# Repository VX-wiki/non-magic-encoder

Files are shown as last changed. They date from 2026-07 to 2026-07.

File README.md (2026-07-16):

# Non-Magic Encoder

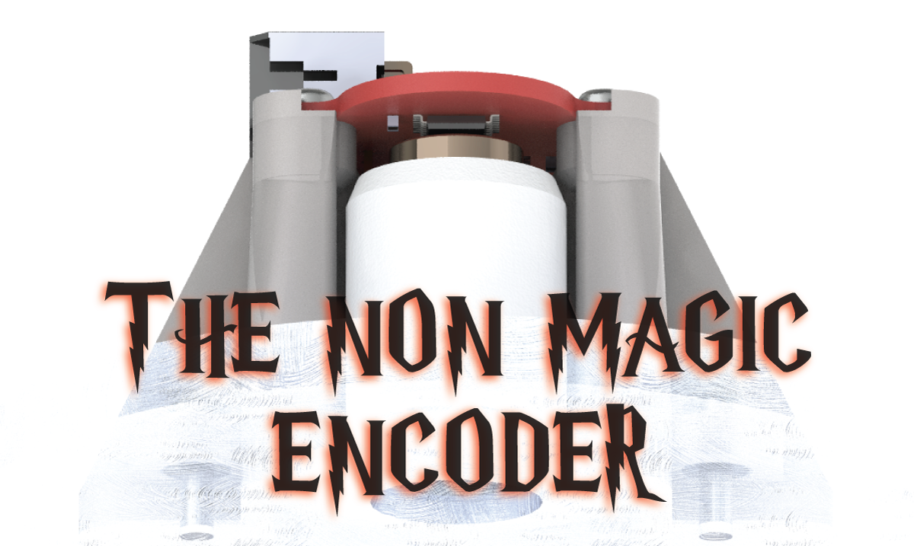
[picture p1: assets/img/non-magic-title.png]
Non-Magic encoder











> ### ⚠️ Read this first: do you actually need one?
>
> **The stock Broadcom optical encoder is magically good when it works.** It is accurate, clean, and there is genuinely nothing wrong with it. Its *only* real weakness is that it is **mechanically fragile**: a delicate optical disc, optics, and aging plastic living in a hot, vibrating drivetrain. If your optical encoder is healthy, **leave it alone**. Nothing here will beat it.
>
> **Non-Magic has no magical properties.** Per the comparison report it does an essentially **identical job**: same current per torque, same heat, same efficiency. It will **not** make your scooter faster, more efficient, or smoother. Treat any apparent "improvement" as noise until proven otherwise.
>
> **This is still hardware under active test.** Non-Magic R1 is community beta with limited hours on a single bike. A lot can still go wrong: installation, adhesives, alignment, calibration, and long-term durability are all unproven at scale. The *one* thing it is meant to bring, better mechanical robustness from having no fragile optical disc, is **plausible but unproven**, and only earns that title after years of real-world service. The only honest reason to fit one today is that your optical encoder has already failed, or you are deliberately experimenting and accept the risk.

<p align="center">
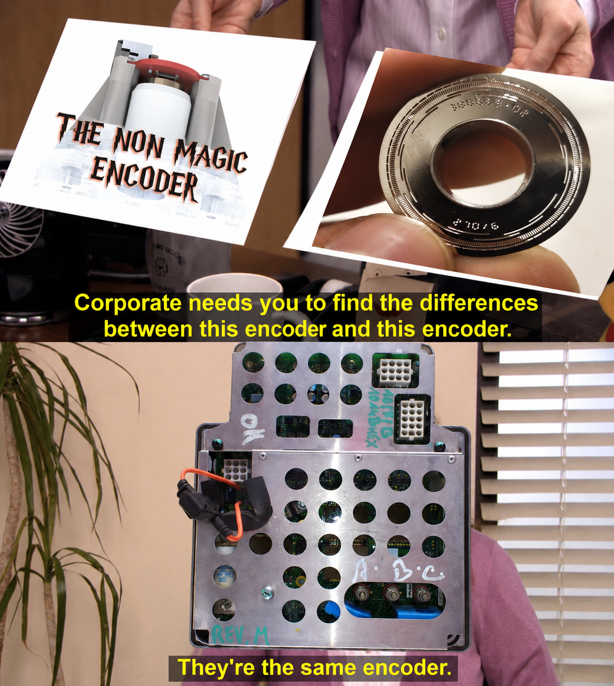
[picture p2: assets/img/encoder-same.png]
Corporate needs you to find the differences between this encoder and this encoder. They're the same encoder.
  
</p>

## Status and scope

Non-Magic R1 is **community-beta DIY hardware that is still actively under test.**

It has been bench-tested and road-tested on the author's single Vectrix VX-1 and, in those limited conditions, has shown no measurable power, efficiency, current, or heat penalty versus the OEM optical encoder. That is the *whole* of the evidence so far: one bike, a modest number of hours, one rider. It is a small-batch maker project, not a mass-produced, durability-qualified, or independently certified vehicle component.

**Expect problems.** Installation, calibration, adhesives, alignment, and long-term durability are all places where it can and may go wrong. The headline claim of better *mechanical robustness* over the optical encoder is plausible but **not yet proven**. It only earns that title after surviving years of heat, vibration, and moisture in service. Until then, assume Non-Magic is, at best, an *equal* to a working optical encoder, with robustness as an unproven bet.

Use it only if you understand the installation, calibration, and testing procedure, and only if you are comfortable being part of that test.

## What is this?

Non-Magic is a calibrated magnetic replacement encoder for the Vectrix VX-1 motor: a practical, mechanically robust drop-in for when the fragile stock optical encoder finally fails.

**Why "Non-Magic"?** There is a lot of magic out there: black-box encoders locked to one motor controller, with proprietary firmware you cannot read, repair, or replace. This is a *non-magical* encoder. It is open hardware you can modify, build, and experiment with as you please.

**Works with any stock motor controller firmware.** Non-Magic fully emulates the original optical encoder's parameters, with line-driver outputs matched to the original. There is nothing to reflash on the controller and no firmware lock-in. It drops in and behaves like the factory encoder. The goal is to **match** the optical encoder from a more mechanically robust platform, not to beat it.

A good encoder matters because the motor controller has to know rotor position before it can switch the windings cleanly. A weak or misaligned encoder can still make the wheel turn, but it can also add current ripple, heat, whine, rough commutation, lower efficiency, and extra stress on the inverter capacitors. The encoder is a small part, but it decides how cleanly the whole motor system works.

The comparison report now covers **two tests**, both against the factory optical encoder on the same stock controller firmware:

- **Bench (no-load).** On the stand, Non-Magic held its own on power and produced a slightly cleaner commutation signature through the main test band, with more sharply defined motor switching, run for run.
- **Road (loaded).** Ridden on public road under real load up to ~110 A, the two encoders were **indistinguishable**: same current for the same torque (within ~1%), the same heat in the inverter and DC-link capacitors, the same cruise/touring consumption (whole-ride energy 689 vs 690 Wh), and the same regen behaviour. The road test closes the bench's main open question: loaded efficiency and component heating.

The honest bottom line: across both tests the calibrated Non-Magic encoder performs **at least as well** as the OEM optical encoder, with no measurable power, efficiency, or heat penalty. "At least as well" is the ceiling of the claim, not a promise of better, and it still rests on a single bike over limited hours. Read the full comparison report here:

[Non-Magic encoder comparison report (rev2: bench + road)](assets/docs/Non-Magic-encoder-comparison-report-rev2-270626.pdf)

## Specifications

| | |
| --- | --- |
| Sensing IC | MT6835, 21-bit high-accuracy magnetic angle encoder |
| Core resolution | 21-bit |
| Accuracy | User auto-calibration with distortion compensation, target INL < ±0.07° |
| Max rotation speed | Up to 120,000 RPM |
| Operating temperature | −40 to +125 °C |
| Output drivers | AM26C31QDR automotive line drivers |
| Output interface | Connections match the original optical encoder |
| Controller firmware | Works with any stock motor controller firmware. Fully emulates the original encoder's parameters, no reflash, no lock-in |
| Mounting | Robust mechanical mount, designed for a hot, vibrating drivetrain |

## Buy DIY Kit

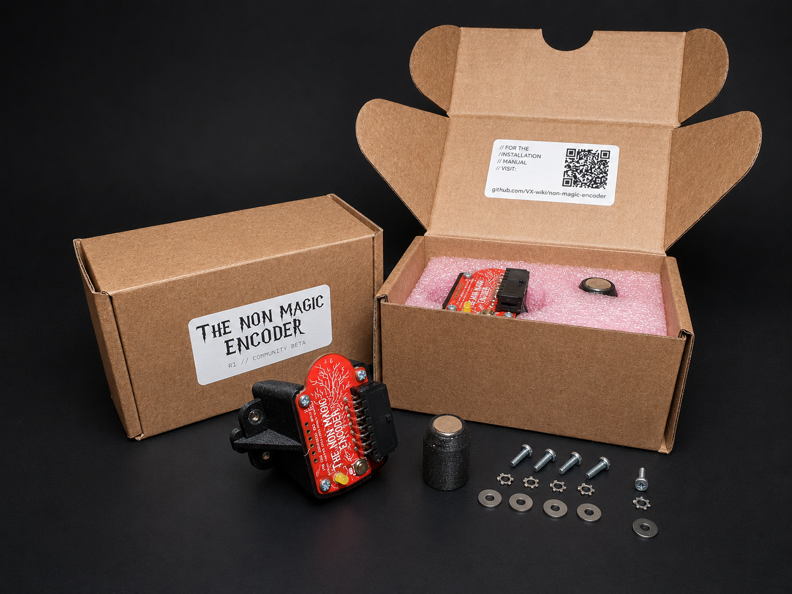
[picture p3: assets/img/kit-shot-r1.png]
Non-Magic encoder DIY kit


<p align="center">
  <a href="https://buy.stripe.com/eVq7sK1AGdGB0a8gIo7Re01">
    
  </a>
  <br>
  <sub>self installation required · community-beta, install at your own risk</sub>
</p>

<p align="center">
  <strong>Proceeds support a non-profit makerspace in Riga, Latvia.</strong><br>
  <sub>The first R1 batch is personally funded by the maintainer; Stripe proceeds after payment processing fees go to the makerspace.</sub>
</p>

> ⚠️ **DIY community-beta kit: read before buying or building.**
>
> This is a limited R1 DIY repair/experimenter kit for experienced Vectrix VX-1 owners. It is **not** a plug-and-play consumer accessory: not type-approved, not independently safety-certified, and not supplied as a certified road-use safety component.
>
> Installation requires correct mechanical fitment, magnet alignment, adhesive use, wiring, encoder self-calibration, and motor-controller offset calibration. Incorrect installation or calibration can cause rough commutation, loss of propulsion, overheating, motor or controller damage, or unsafe vehicle behaviour.
>
> Buy only if you can install, inspect, calibrate, and test it yourself. Start with the wheel lifted, test gently, and stop using it immediately if you hear abnormal noise, feel rough running, see faults, or notice unusual heat.
>
> Nothing here limits any mandatory rights or remedies that cannot legally be excluded.

Every board is **tested, programmed, and conformal coated** before it ships. The kit includes **all required parts except threadlocker and adhesive** (listed as consumables below).

## PCB

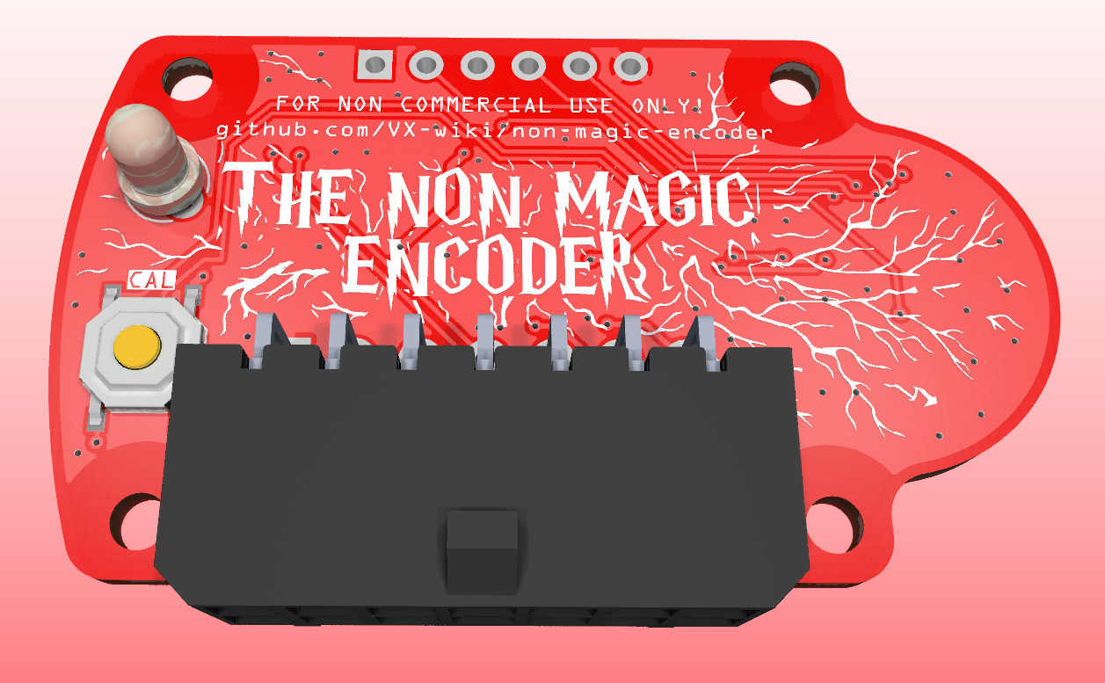
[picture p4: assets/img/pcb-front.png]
Non-Magic PCB front


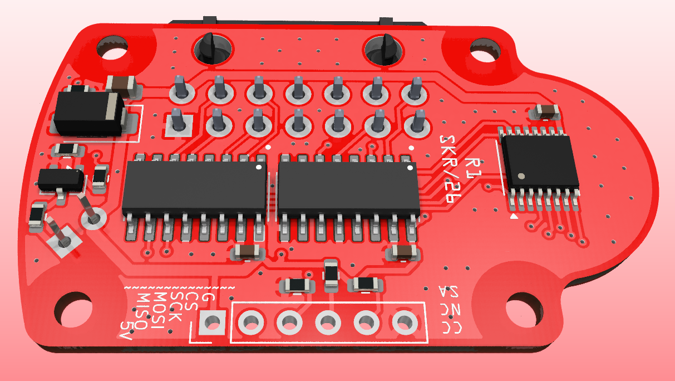
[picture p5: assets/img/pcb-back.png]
Non-Magic PCB back


## How to Install and Use

> ⚠️ **Safety first: read before you touch anything.**
>
> - **Always on the centre stand.** Every calibration and test step below is done with the bike on its centre stand and the **driven (rear) wheel off the ground and free to spin**. The motor can spin that wheel on its own during offset calibration, so never do this with the wheel able to drive the bike.
> - **High voltage.** The Vectrix runs on high-voltage traction electronics. Treat the battery, controller, and wiring as live and dangerous at all times, and take every sane high-voltage precaution whenever you work on the bike.

Installation walkthrough video:

https://github.com/user-attachments/assets/6c1a84cd-9490-44e6-9311-1ca9467ff3d4

A key advantage of Non-Magic is that it **self-calibrates once installed**. The on-board MT6835 builds its own angle-error correction map while the rotor turns slowly. You just spin the rear wheel at roughly 5 km/h with a hand drill pressed against the tyre and hold the calibration button. No special rig, no PC required for this step.

### 1. Mechanical installation

1. **Remove the original encoder assembly.**
2. **Clean the area thoroughly.** No dust, grease, oil, or other contaminants may remain in the motor encoder cavity. A clean, dry surface is critical for both the adhesive bond and the magnetic reading.
3. **Install the magnet holder.** Apply adhesive and push the magnet holder on until the motor shaft bottoms out inside it. Watch the slot in the shaft and the magnet holder; they must align cleanly. Allow the adhesive to set if possible.
4. **Attach the encoder assembly to the motor case.** Use threadlocker on the bolts. Fit each bolt with a wide washer and a serrated washer. **Do not overtighten.**
5. **Connect the encoder connector.**

There are **two separate calibrations**, and they must not be confused:

- **Encoder ASIC self-calibration** (Section 2) calibrates the **encoder**. It runs on the encoder's own MT6835 chip and corrects the magnetic sensor's per-revolution angle-error map, using the **encoder's calibration button and LED**.
- **Motor offset calibration** (Section 3) calibrates the **inverter**. It runs on the Vectrix motor controller, either in diagnostic software or via the throttle/brake/ignition "combo", and teaches the controller the fixed angle between encoder zero and the rotor's magnetic zero.

Do both, in this order. They are different procedures on different hardware; the encoder button does not trigger the controller offset cal, and the controller combo does not trigger the ASIC self-cal.

### 2. Encoder ASIC self-calibration (on the encoder)

1. **Power on the bike, but do not try to start it.**
2. **Turn the wheel by hand and watch the LED.** It should give **5 pulses per wheel revolution**. If it does, the magnet and alignment are good.
3. **Run the calibration spin.** Put the bike on the centre stand and spin the rear wheel with a hand drill pressed against the tyre, holding roughly **5 km/h** (read off the dash or scooter diagnostic software).
4. **Hold the calibration button.** Calibration needs **more than 64 rotations** to complete; expect to hold the button for under ~20 seconds. **THE SPEED TARGET IS APPROX 10-30-ish km/h, so no need to be very precise. If you are too slow or fast- it will just fail and let you know with the led** The LED shows progress:

   | LED state | Meaning |
   | --- | --- |
   | Half brightness | Calibration in progress |
   | Dim | Calibration failed |
   | Full on | Calibration succeeded |

5. **Turn the bike fully off** once calibration succeeds.

### 3. Motor offset calibration (on the inverter)

After the on-board self-cal, the motor controller still needs its own encoder-offset calibration.

**With the Vectrix diagnostics software:** turn the bike on and run the encoder calibration from the diagnostic application. Note this needs a **PeakCAN cable** to talk to the controller. If you don't have one, you can't use the software, so use the combo procedure below instead.

**Without software, the built-in combo procedure:** the controller has a hidden calibration mode you trigger straight from the bars, no cable or software required. (This is the same throttle/brake/ignition combo Vectrix documented for the original optical encoder; it works identically here.)

1. Put the bike on its **centre stand** and confirm the rear wheel is off the ground, free to spin, and the bike is stable.
2. Fold up the side-stand / kickstand.
3. Make sure the ignition key is in the **OFF** position.
4. Press the kill switch to the **RUN** position.
5. Turn the throttle **fully open** and squeeze the **left brake** lever, and hold both.
6. While still holding throttle and brake, turn the ignition **ON**.
7. Keep holding until the dashboard activates and the **WRENCH** icon / tell-tale light stays on, then release the throttle and brake.
8. Calibration starts automatically: the wheel begins to rotate and the speedometer needle sweeps from 0 km/h up to 120 km/h and back to zero.
9. After a few seconds the **WRENCH** icon disappears. Calibration is done.
10. If the process repeats itself over and over, the encoder cannot find a valid calibration; it requires inspection, cleaning, or replacement.

> **Caution:** the bike is still in GO mode during and after this procedure. Turning the throttle will activate the motor.

Then test gently first, listening for rough commutation or abnormal motor/controller heat.

> **Note: check your phase wiring.** The author's bike came equipped with a "magic" commercial magnetic encoder as purchased, and its motor phase wires were connected A-B, B-C, C-A. Neither the optical nor the magnetic encoder would work until the phases were swapped back to their respective factory positions: A-A, B-B, C-C. If the motor refuses to run or commutates badly regardless of encoder calibration, verify the phase wiring is in its correct factory order before troubleshooting the encoder further.

Installation consumables:

| No | Name | Qty | Notes | Link |
| ---: | --- | ---: | --- | --- |
| 1 | Threadlocker, blue or red | as needed | For encoder holder to motor case | commodity |
| 2 | Magnet holder to motor adhesive | as needed | Preferred order: automotive gasket maker, toughened cyanoacrylate, two-part epoxy, threadlocker | commodity |

## Make Your Own

Or make your own. The full design sources are below.

> ⚠️ **License first.** These files are released under **CC BY-NC-SA 4.0**. You may build, modify, and share them, but you may **not sell them or profit in any way**, and any derivative must stay under the same license. See [License](#license). No magic, no freeloading.

**Total cost is roughly €25–60 per unit**, depending on how you scale and source the parts and what tools and materials you already have on hand.

The DIN fasteners are standard commodity parts; source them from any supplier by their DIN number.

| No | Name | Image | Qty | Notes | Link |
| ---: | --- | :---: | ---: | --- | --- |
| 1 | Main PCB | Main PCB front | 1 | Gerbers + assembly files | [production archive](hardware/kicad/production/non-magic-encoder-r1.zip) |
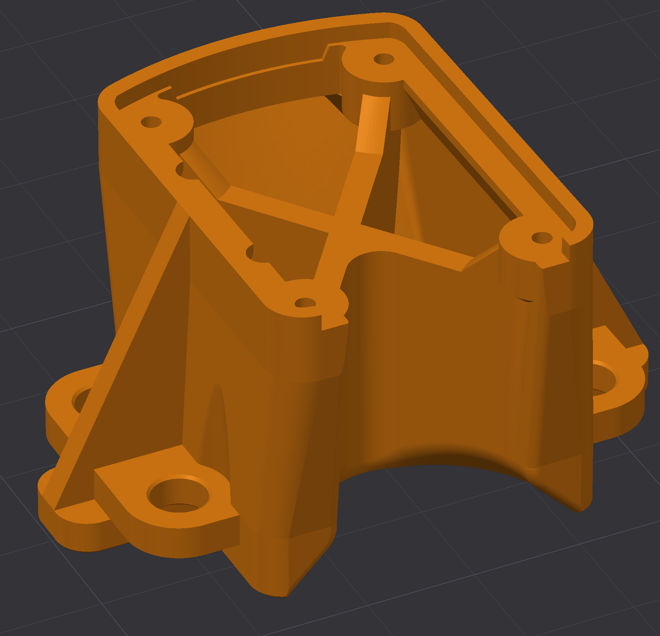
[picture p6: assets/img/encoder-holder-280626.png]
Printed PCB holder
| 2 | Printed PCB holder* |  | 1 | FDM PA6-GF, PA6-CF, PPS-CF, or MFJ PA12-GB. IMPORTANT! | [STL](hardware/printed-parts/encoder-printed-holder-r1.STL) |
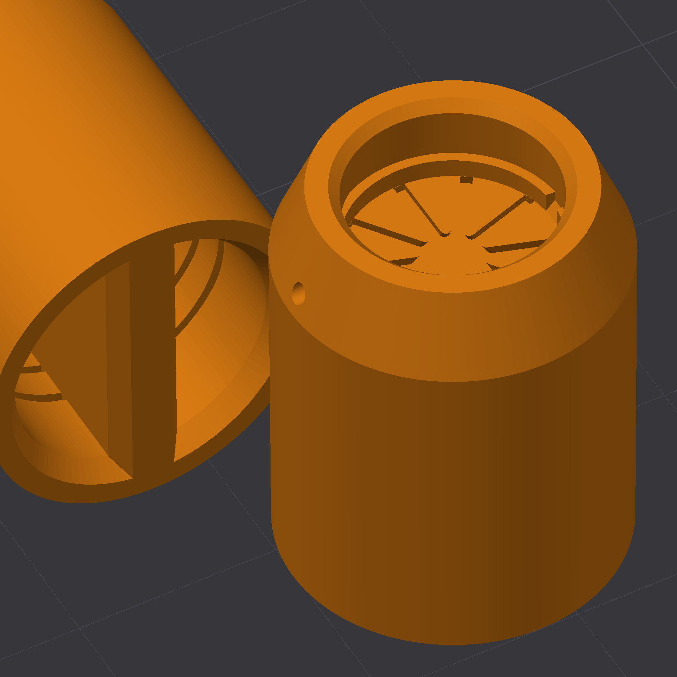
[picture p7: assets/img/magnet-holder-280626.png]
Printed magnet holder
| 3 | Printed magnet holder* |  | 1 | FDM PA6-GF, PA6-CF, PPS-CF, or MFJ PA12-GB. IMPORTANT! | [STL](hardware/printed-parts/magnet-holder-r1.STL) |
| 4 | 3M DP8910NS adhesive | | 0.1 g | Bonds the magnet to the printed nylon holder. Alternate adhesive can be used, but it is risky; see note below | [3M](https://www.3m.com/) |
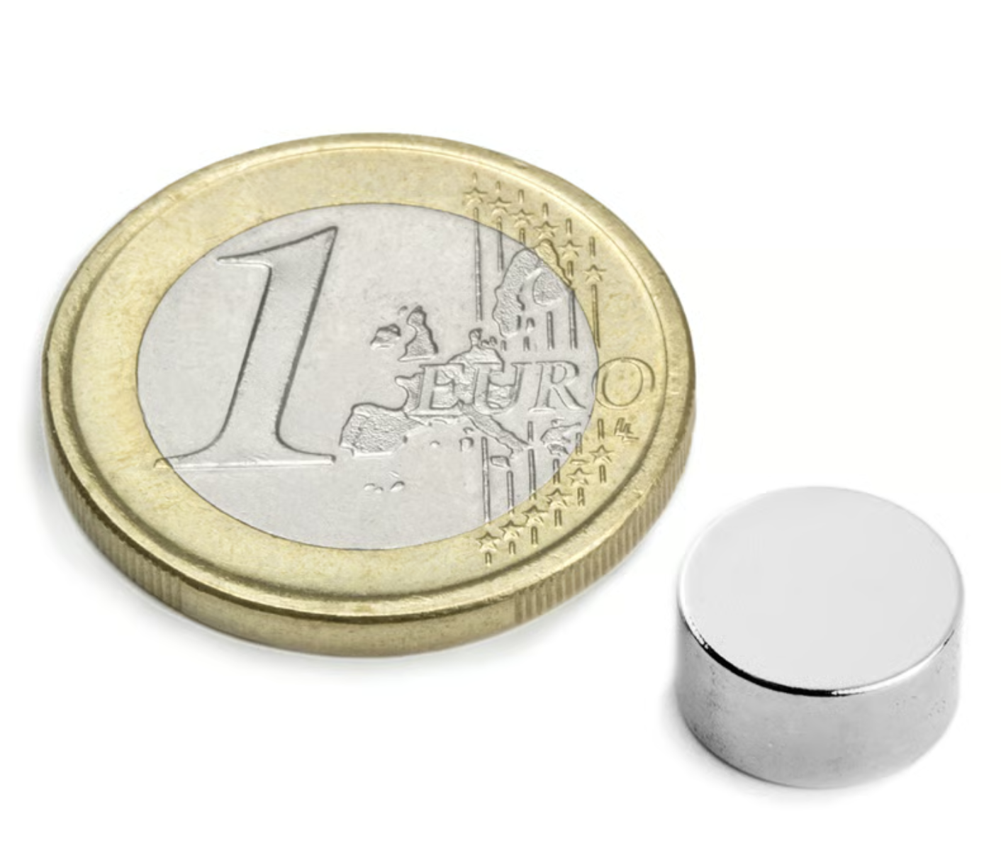
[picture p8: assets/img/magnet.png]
10x5 neodymium magnet
| 5 | 10x5 neodymium magnet |  | 1 | N45 or better, diametrically magnetized | commodity |
| 6 | Sleeve DIN 7340 | | 4 | Cu, 2.6 x 5 x 3 | commodity |
| 7 | Washer DIN 9021 | | 4 | M2.5, OD8 | commodity |
| 8 | Washer DIN 6798 Type A | | 4 | M2.5 | commodity |
| 9 | Bolt DIN 7985 | | 4 | M2.5, length to suit installation | commodity |
| 10 | Screw DIN 7981 ST 2.0 x 6 | | 4 | EJOT PT is better | commodity |
| 11 | Conformal coating | | as needed | Weatherproof the populated PCB; see note below | commodity |

*The encoder lives in a harsh environment. You must use glass-filled high-performance material for the encoder support. PA6-GF is used in the current units. Standard SLS PA12 or PA11 may not be up to the task.

**Why the 3M DP8910NS adhesive matters:** nylon (PA6 through PA12) is a *low surface energy* plastic, so most common adhesives will not key into it and the bond fails. DP8910NS is formulated specifically for low-energy substrates like nylon and polypropylene, which is why it is the recommended choice for bonding the magnet to the printed holder. Substituting a general-purpose adhesive is the most likely way to end up with magnet delamination.

**Conformal coating is important.** The encoder lives in a harsh place: heat, vibration, moisture, and contamination. Conformal coating the populated PCB is essential weatherproofing that protects against corrosion and conductive dirt. Factory-built kits ship already coated; if you build your own, do not skip this step.

### Design files

Everything needed to fabricate, assemble, or modify the board:

| File | Description |
| --- | --- |
| [Schematic (PDF)](hardware/non-magic-encoder-r1-schematic.pdf) | R1 schematic |
| [Production archive (ZIP)](hardware/kicad/production/non-magic-encoder-r1.zip) | Gerbers, BOM, and pick-and-place for fabrication |
| [KiCad project](hardware/kicad/) | Editable sources (`.kicad_pro`, `.kicad_sch`, `.kicad_pcb`), libraries, and footprints |
| [Board STEP model](hardware/encoder-pcb-r1.step) | 3D model of the assembled PCB |
| [PCB holder STL](hardware/printed-parts/encoder-printed-holder-r1.STL) | Printed encoder support (glass-filled material, see note above) |
| [Magnet holder STL](hardware/printed-parts/magnet-holder-r1.STL) | Printed magnet carrier (glass-filled material, see note above) |
| [MT6835 datasheet](hardware/kicad/docs/MT6835_Rev.1.3.pdf) | Sensing IC reference |

## Informal Risk Assessment

A short FMEA-style note on the failure modes that actually matter on this hardware. This is not an ISO 26262 compliance claim, safety case, or certification. Severity, likelihood, and controllability are qualitative.

| Failure mode | Cause | Effect | Severity | Risk reduction |
| --- | --- | --- | --- | --- |
| Bad commutation | Magnet misalignment or skipped auto-calibration | Motor switches at the wrong angle, drawing excess current and overheating the motor and controller | Medium-High | Verify magnet centering and air gap, run the auto-calibration before riding, test first with the wheel lifted and watch for abnormal heat |
| Loss of board power | Cracked or shorted MLCC on the PCB shorts the supply and trips the upstream resettable fuse | Encoder goes dead, controller loses position, **motor coasts to a halt** (no torque, not a runaway) | Medium | Use quality MLCCs, avoid board flex during assembly and mounting, handle the populated PCB carefully |
| Mechanical failure | Magnet delamination: the magnet's adhesive bond to its holder lets go | Position signal is lost or wrong, propulsion drops out | Medium | Use the ranked adhesives with proper surface prep, use only glass-filled holder material, inspect after the first heat cycles |

Before riding: confirm the magnet is centred, run auto-calibration, and do the first run with the driven wheel lifted and a safe way to cut power. Treat any suspected encoder fault as stop-use until inspected. Road or public-use suitability is outside the scope of this project.

## Getting help

Two ways to get help or report a problem:

- **Open an issue.** [Create an issue in this repo](../../issues/new) for bugs, broken links, install trouble, or questions. This is the best place for anything others might hit too.
- **Chat with the community.** Reach out on WhatsApp in the **Open Source Magic Encoder** group, part of the wider **Vectrix Worldwide** community. It's the fastest way to get hands-on install and calibration help from other owners.

## Contributing

Contributions are welcome. Fork the repo, make your changes, and open an issue or pull request:

- **Found a bug or have an idea?** Open an issue first so it can be discussed.
- **Improved the hardware, holders, or docs?** Fork it, commit your changes, and open a pull request from your fork.

Anything you contribute is released under the same **CC BY-NC-SA 4.0** license as the rest of the project (see below), so improvements stay open for everyone.

## License

This project is licensed under the Creative Commons Attribution-NonCommercial-ShareAlike 4.0 International license (CC BY-NC-SA 4.0). See [LICENSE](LICENSE).

In plain terms:

- **Attribution.** You may use, build, and adapt this design, as long as you credit the project.
- **NonCommercial.** You may **not** sell these encoders or profit from them in any way. This is deliberate: the kits exist to fund a non-profit makerspace, not to seed a competing product.
- **ShareAlike.** If you modify and share the design, you must release your version under the same license, so improvements stay open for everyone.

**A simple test for what's allowed:** if you can order, say, 5–10 units from China and give them away to friends or others *at cost*, making no profit, taking no salary, charging nothing beyond what the parts and fabrication actually cost you, then the answer is **yes, that's fine**. The moment you mark them up, pay yourself, or otherwise come out ahead, it stops being NonCommercial and is no longer permitted.

This keeps the encoder in the spirit of the name: open to modify, build, and experiment with, but never to lock up or sell.

## Disclaimer

No warranties are provided. This is experimental hardware intended for off-road, testing, research, and maker use only. It is not certified as a road-use safety component.

Build, install, calibrate, and use it entirely at your own risk. You are responsible for checking fitment, alignment, wiring, calibration, local legality, and safe operation. The authors and contributors are not responsible for damage, injury, loss, or any other consequences from making, installing, modifying, or using this encoder.

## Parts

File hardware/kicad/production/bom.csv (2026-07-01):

Designator | Footprint | Quantity | Value | LCSC Part #
C2 | 0805 | 1 | 10u | C15850
C6, C7, C8 | 0603 | 3 | 100n | C14663
D1 | D_SMA | 1 | SMAJ5.0A | C5189780
D4 | LED_D3.0mm_Clear | 1 | LED
J1 | CONN-TH_14P-P3.00_HC-MX3.0-2X7AW | 1 | Conn_02x07_Odd_Even | C3294388
Q1 | SOT-23 | 1 | 2N7002 | C8545
R10 | 0603 | 1 | 100R | C4177
R11 | 0603 | 1 | 1k 0603 | C21190
R12, R6, R7, R8, R9 | 0603 | 5 | 100k | C25803
SW1 | SW-SMD_4P-L5.1-W5.1-P3.70-LS6.5-TL_H1.5 | 1 | CAL | C318884
U1 | TSSOP-16_4.4x5mm_P0.65mm | 1 | MT6835 | C2932578
U7, U8 | SOIC127P600X175-16N | 2 | AM26C31QDR | C337769

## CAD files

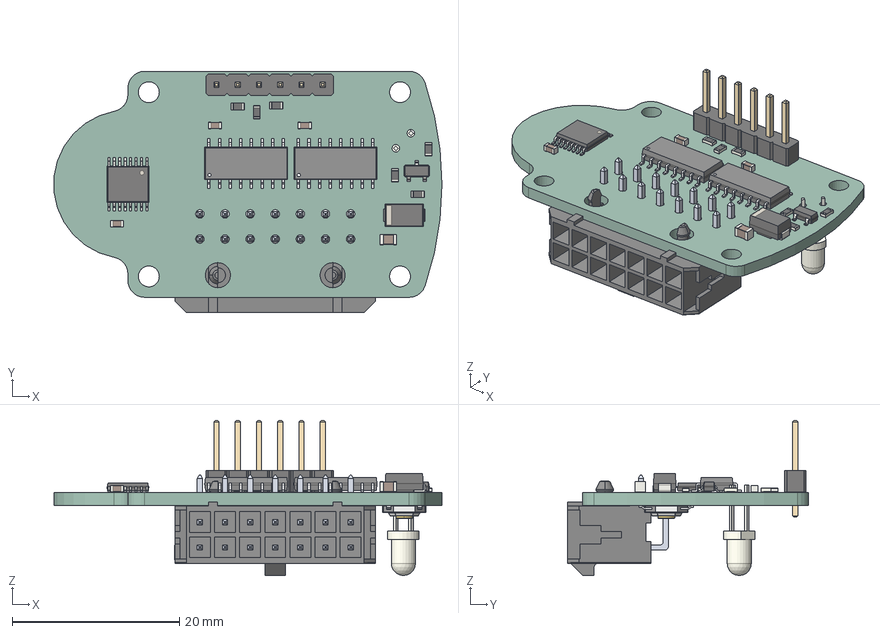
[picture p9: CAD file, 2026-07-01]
hardware/encoder-pcb-r1.step
46.3 x 28.8 x 18.5 mm
R_0603_1608Metric x 6
Body001 (Mirror #1) x 16
XY-plane x 24
X-axis x 24
PinHeader_1x06_P254mm_Vertical
C_0603_1608Metric x 3
SOT-23
D_SMA
C_0805_2012Metric
TSSOP-16_4.4x5mm_P0.65mm
SW-SMD_4P-L5.1-W5.1-P3.70-LS6.5-TL_H1.5
LED_D3.0mm_Clear
CONN-TH_14P-P3.00_HC-MX3.0-2X7AW
non-magic-encoder-r1_PCB

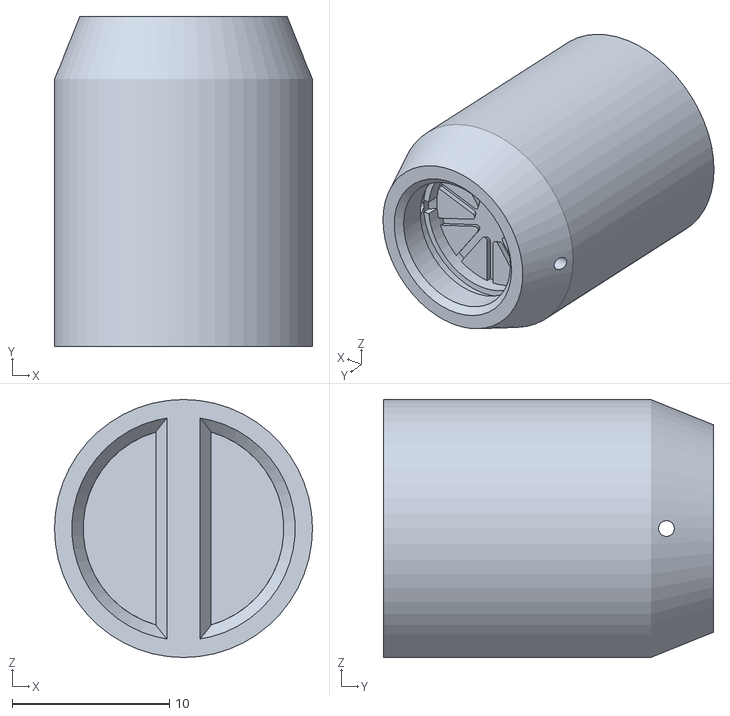
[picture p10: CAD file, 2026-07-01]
hardware/printed-parts/magnet-holder-r1.STL
16.4 x 21.0 x 16.4

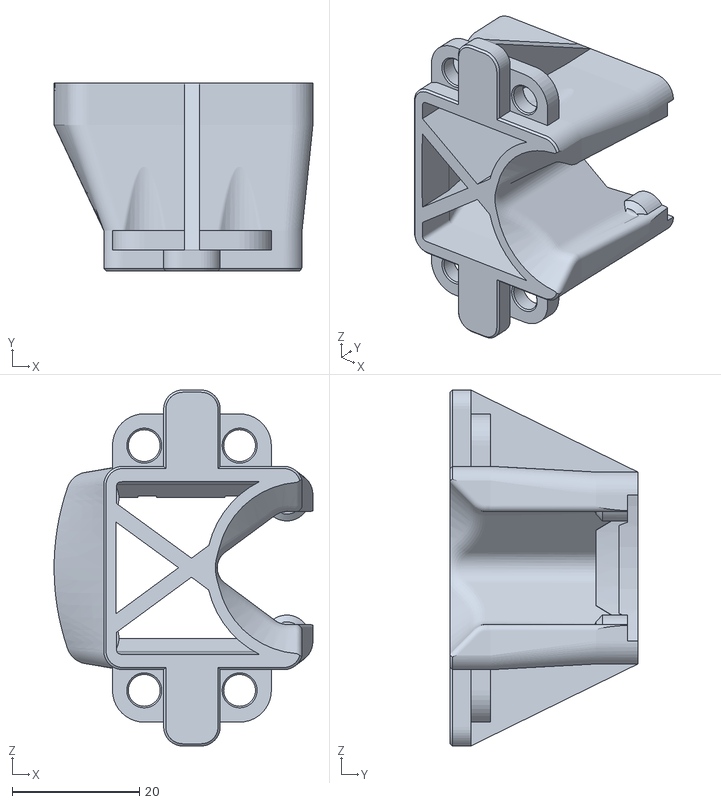
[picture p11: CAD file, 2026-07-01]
hardware/printed-parts/encoder-printed-holder-r1.STL
40.7 x 29.5 x 56.0

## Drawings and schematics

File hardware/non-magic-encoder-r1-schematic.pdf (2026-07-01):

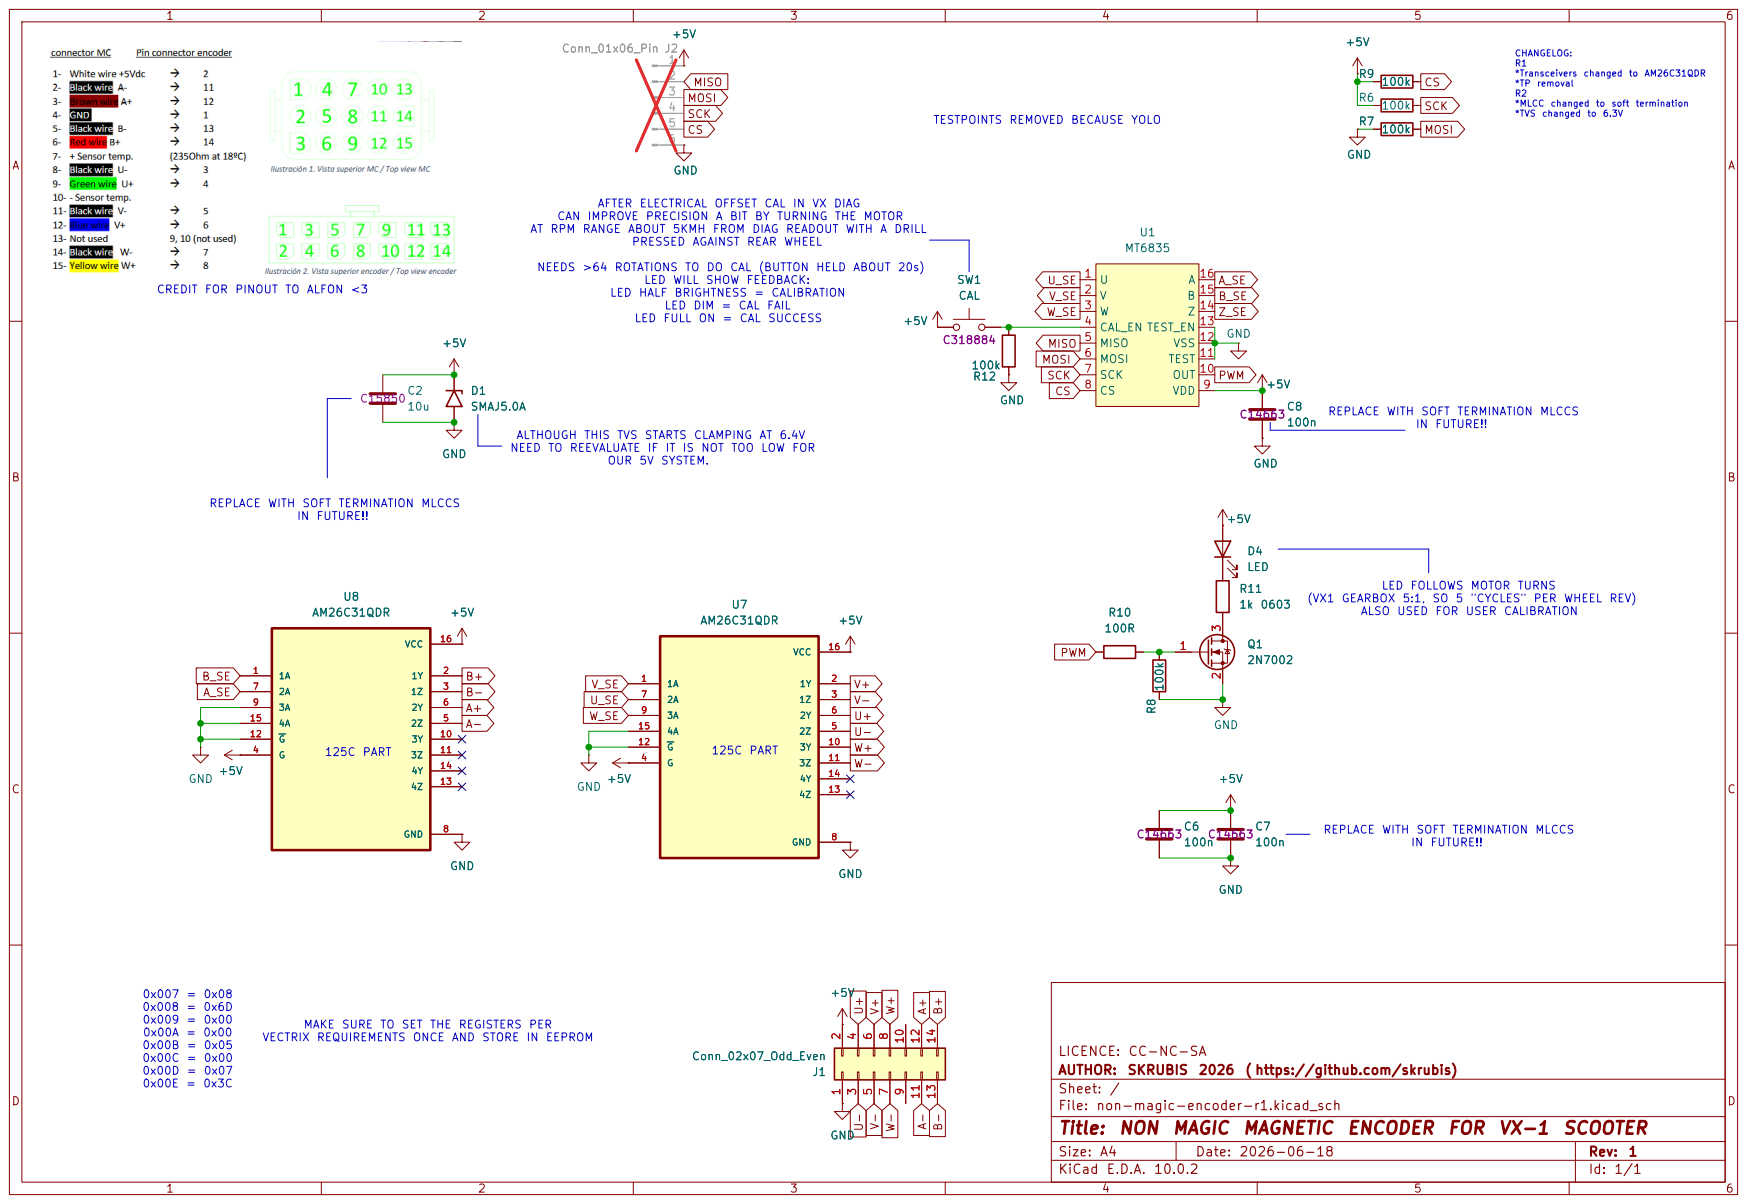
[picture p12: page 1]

LED FULL ON = CAL SUCCESS Conn_01x06_Pin J2
CS MOSI U_SE U-

*MLCC changed to soft termination
*TVS changed to 6.3V

TESTPOINTS REMOVED BECAUSE YOLO

CAN IMPROVE PRECISION A BIT BY TURNING THE MOTOR
AT RPM RANGE ABOUT 5KMH FROM DIAG READOUT WITH A DRILL PRESSED AGAINST REAR WHEEL NEEDS >64 ROTATIONS TO DO CAL (BUTTON HELD ABOUT 20s) LED WILL SHOW FEEDBACK: LED HALF BRIGHTNESS = CALIBRATION

CREDIT FOR PINOUT TO ALFON <3

LED DIM = CAL FAIL

ALTHOUGH THIS TVS STARTS CLAMPING AT 6.4V NEED TO REEVALUATE IF IT IS NOT TOO LOW FOR OUR 5V SYSTEM. MAKE SURE TO SET THE REGISTERS PER

REPLACE WITH SOFT TERMINATION MLCCS

LED FOLLOWS MOTOR TURNS

(VX1 GEARBOX 5:1, SO 5 "CYCLES" PER WHEEL REV) ALSO USED FOR USER CALIBRATION

VECTRIX REQUIREMENTS ONCE AND STORE IN EEPROM

LICENCE: CC-NC-SA
AUTHOR: SKRUBIS 2026 ( https://github.com/skrubis)
Sheet: /
File: non-magic-encoder-r1.kicad_sch
Title: NON MAGIC MAGNETIC ENCODER FOR VX-1 SCOOTER

Size: A4 | Rev: 1
KiCad E.D.A. 10.0.2 | Id: 1/1

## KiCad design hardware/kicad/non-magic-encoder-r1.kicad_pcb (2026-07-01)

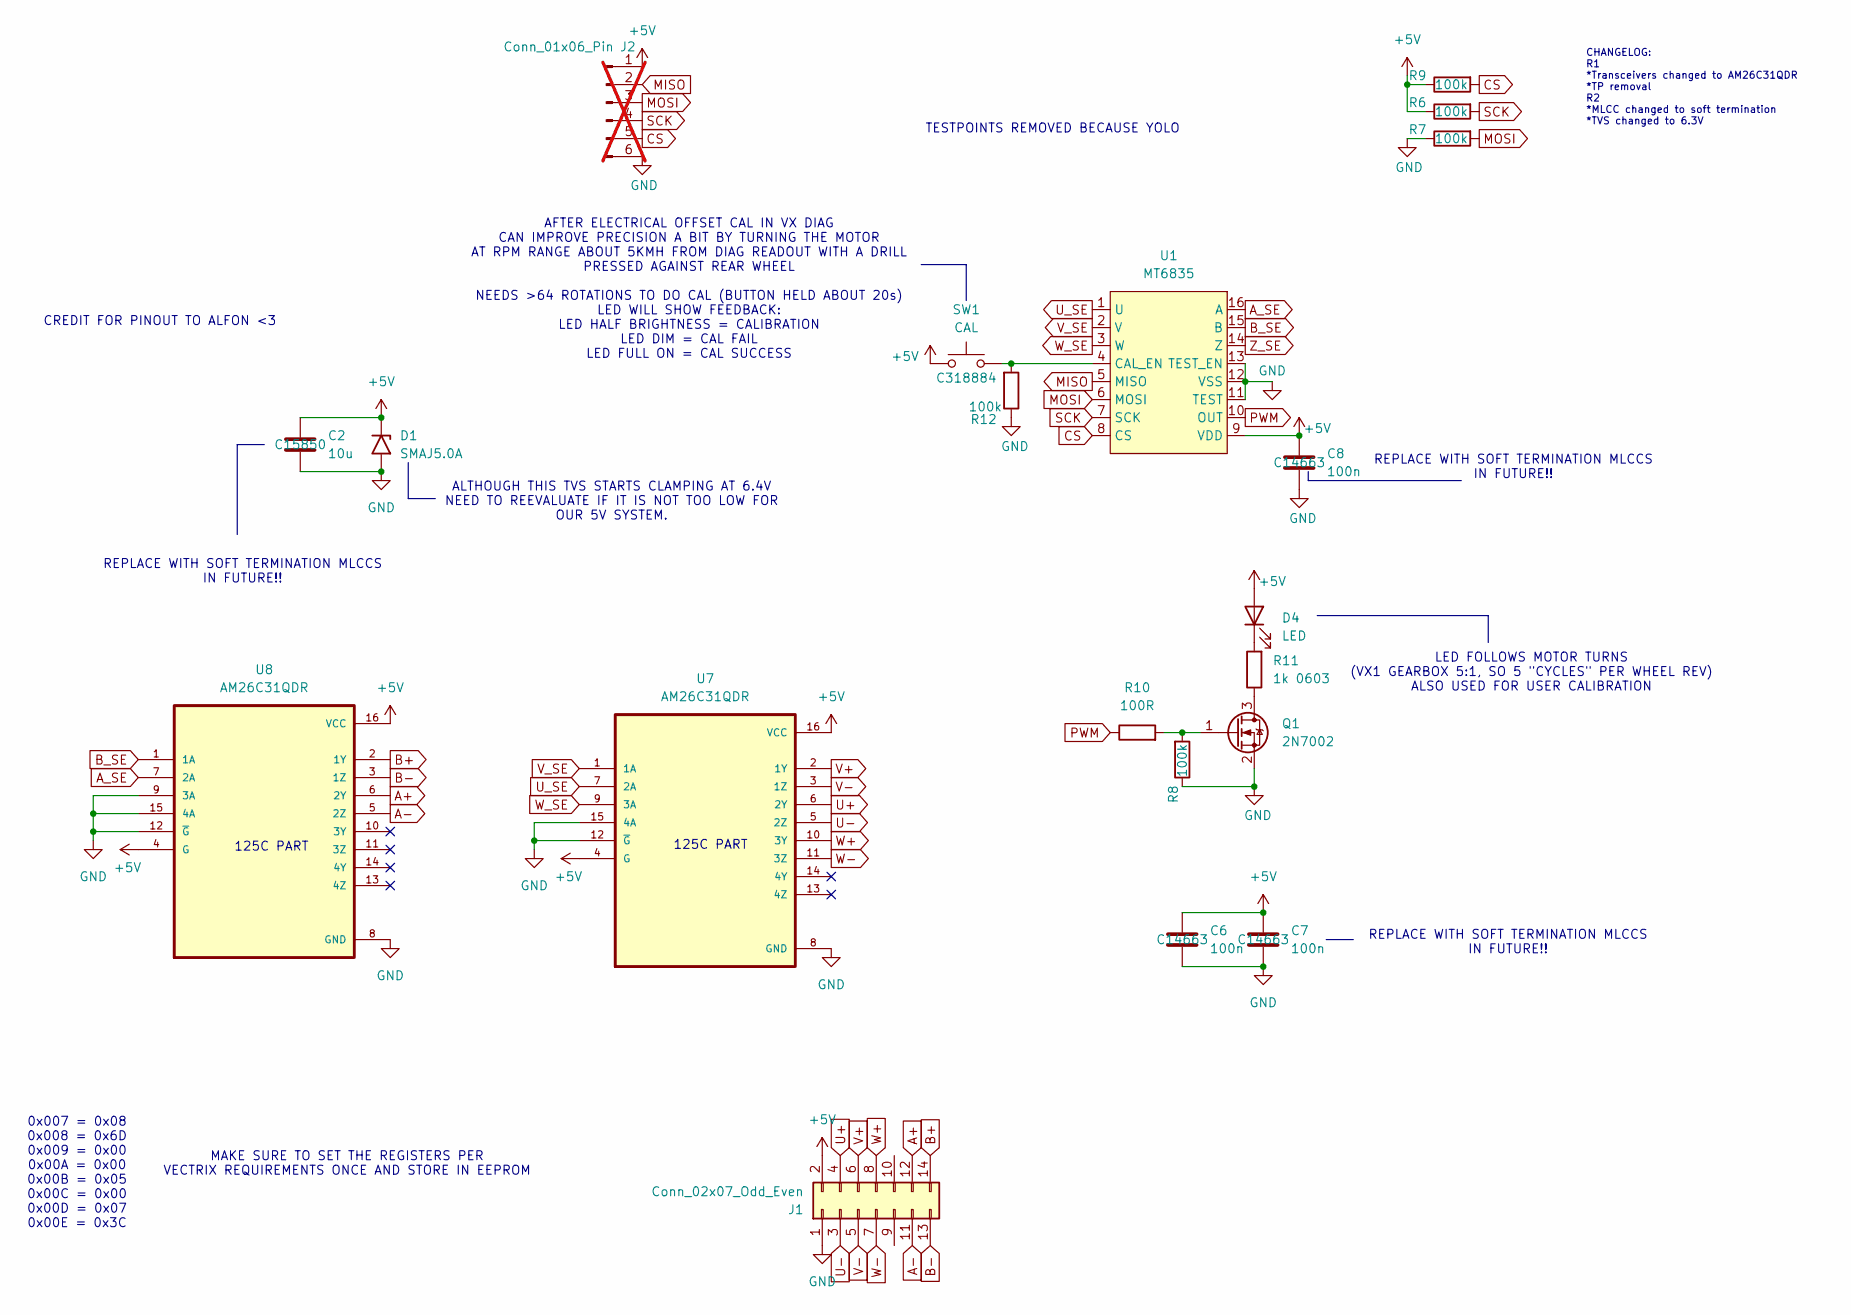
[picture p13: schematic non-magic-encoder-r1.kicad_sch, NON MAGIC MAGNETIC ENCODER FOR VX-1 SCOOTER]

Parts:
C2: 10u; C_0805_2012Metric; LCSC C15850
C6, C7, C8: 100n; C_0603_1608Metric; LCSC C14663
D1: SMAJ5.0A; D_SMA; LCSC C5189780
D4: LED; LED_D3.0mm_Clear
J1: Conn_02x07_Odd_Even; CONN-TH_14P-P3.00_HC-MX3.0-2X7AW; LCSC C3294388
J2: Conn_01x06_Pin; PinHeader_1x06_P2.54mm_Vertical; not fitted
Q1: 2N7002; SOT-23; LCSC C8545
R6, R7, R8, R9, R12: 100k; R_0603_1608Metric; LCSC C25803
R10: 100R; R_0603_1608Metric; LCSC C4177
R11: 1k 0603; R_0603_1608Metric; LCSC C21190
SW1: CAL; SW-SMD_4P-L5.1-W5.1-P3.70-LS6.5-TL_H1.5; LCSC C318884
U1: MT6835; TSSOP-16_4.4x5mm_P0.65mm; LCSC C2932578
U7, U8: AM26C31QDR; SOIC127P600X175-16N; LCSC C337769

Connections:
+5V: C2.1, C6.1, C7.1, C8.1, D1.1 (A1), D4.2 (A), J1.2, J2.1, R6.1, R9.1, SW1.1, U1.9 (VDD), U7.4 (G), U7.16 (VCC), U8.4 (G), U8.16 (VCC)
A+: J1.12, U8.6 (2Y)
A-: J1.11, U8.5 (2Z)
A_SE: U1.16 (A), U8.7 (2A)
B+: J1.14, U8.2 (1Y)
B-: J1.13, U8.3 (1Z)
B_SE: U1.15 (B), U8.1 (1A)
CS: J2.5, R9.2, U1.8 (CS)
GND: C2.2, C6.2, C7.2, C8.2, D1.2 (A2), J1.1, J2.6, Q1.2 (S), R7.1, R8.1, R12.1, U1.11 (TEST), U1.12 (VSS), U1.13 (TEST_EN), U7.8 (GND), U7.12 (~G), U7.15 (4A), U8.8 (GND), U8.9 (3A), U8.12 (~G), U8.15 (4A)
MISO: J2.2, U1.5 (MISO)
MOSI: J2.3, R7.2, U1.6 (MOSI)
unnamed: D4.1 (K), R11.2
unnamed: Q1.3 (D), R11.1
unnamed: Q1.1 (G), R8.2, R10.2
unnamed: R12.2, SW1.2, U1.4 (CAL_EN)
PWM: R10.1, U1.10 (OUT)
SCK: J2.4, R6.2, U1.7 (SCK)
U+: J1.4, U7.6 (2Y)
U-: J1.3, U7.5 (2Z)
U_SE: U1.1 (U), U7.7 (2A)
V+: J1.6, U7.2 (1Y)
V-: J1.5, U7.3 (1Z)
V_SE: U1.2 (V), U7.1 (1A)
W+: J1.8, U7.10 (3Y)
W-: J1.7, U7.11 (3Z)
W_SE: U1.3 (W), U7.9 (3A)
Z_SE: U1.14 (Z)

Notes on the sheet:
REPLACE WITH SOFT TERMINATION MLCCS IN FUTURE!!
MAKE SURE TO SET THE REGISTERS PER VECTRIX REQUIREMENTS ONCE AND STORE IN EEPROM
CREDIT FOR PINOUT TO ALFON <3
LED FOLLOWS MOTOR TURNS (VX1 GEARBOX 5:1, SO 5 "CYCLES" PER WHEEL REV) ALSO USED FOR USER CALIBRATION
0x007 = 0x08 0x008 = 0x6D 0x009 = 0x00 0x00A = 0x00 0x00B = 0x05 0x00C = 0x00 0x00D = 0x07 0x00E = 0x3C
125C PART
CHANGELOG: R1 *Transceivers changed to AM26C31QDR *TP removal R2 *MLCC changed to soft termination *TVS changed to 6.3V
TESTPOINTS REMOVED BECAUSE YOLO
ALTHOUGH THIS TVS STARTS CLAMPING AT 6.4V NEED TO REEVALUATE IF IT IS NOT TOO LOW FOR OUR 5V SYSTEM.
AFTER ELECTRICAL OFFSET CAL IN VX DIAG CAN IMPROVE PRECISION A BIT BY TURNING THE MOTOR AT RPM RANGE ABOUT 5KMH FROM DIAG READOUT WITH A DRILL PRESSED AGAINST REAR WHEEL NEEDS >64 ROTATIONS TO DO CAL (BUTTON HELD ABOUT 20s) LED WILL SHOW FEEDBACK: LED HALF BRIGHTNESS = CALIBRATION LED DIM = CAL FAI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

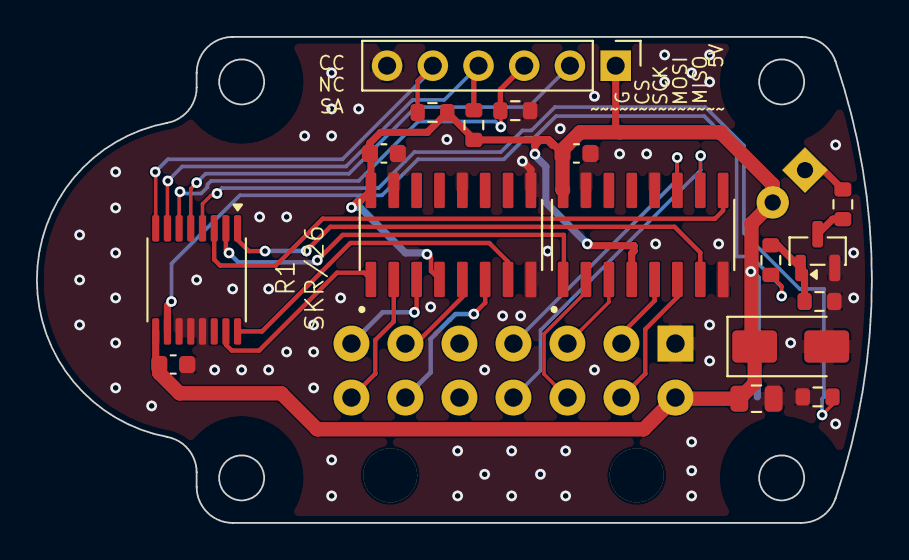
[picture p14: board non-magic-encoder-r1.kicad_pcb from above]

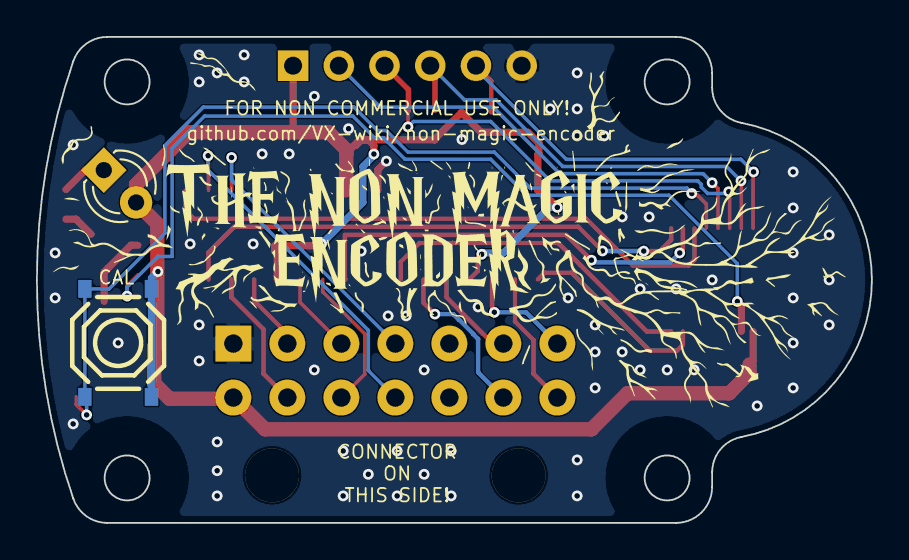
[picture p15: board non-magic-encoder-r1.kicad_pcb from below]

Board: 2 copper layers, 46.4 x 27.0 mm, 20 parts (3 on the bottom side), 26 nets.
